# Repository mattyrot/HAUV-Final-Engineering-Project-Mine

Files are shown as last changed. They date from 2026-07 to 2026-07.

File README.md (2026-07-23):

# HAUV — Hybrid Autonomous Underwater Vehicle

A compact underwater robot you drive from a laptop with a game controller — or
point at a spot on the map and let it swim there by itself.

It runs **ROS 2 Foxy** across two computers, talks to **QGroundControl** over
either an Ethernet tether or an **acoustic (USBL) link**, and looks after itself
with a leak failsafe that surfaces the vehicle without any help from the operator.

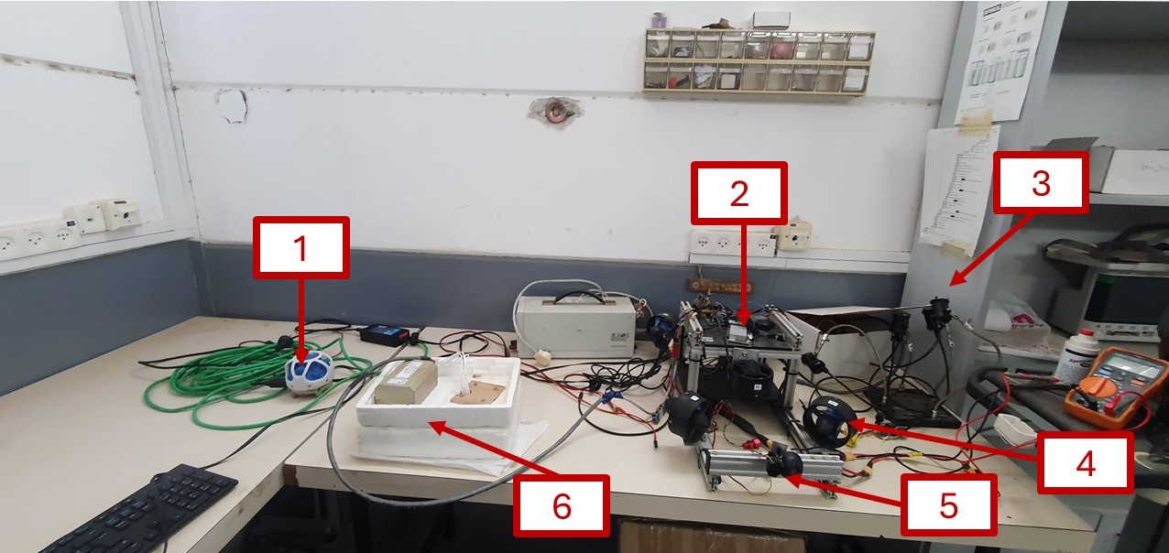
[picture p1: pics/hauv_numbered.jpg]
The HAUV and its main parts


| # | Part | What it does |
|---|---|---|
| 1 | **Subsonus (USBL modem)** | Acoustic link to the surface — control with no cable |
| 2 | **Electronics tray** | The two computers and their boards |
| 3 | **Lights** | Two switchable sets |
| 4 | **Thrusters** | 6 × Blue Robotics T200 |
| 5 | **Camera** | Live video to the operator screen |
| 6 | **DVL** | Speed over the sea floor |

---

## Highlights

- **Two control links** — Ethernet tether (full telemetry + video) or acoustic
  USBL (compact telemetry, no cable, no video).
- **Auto-GOTO / Guided mode** — click a point in QGC, the vehicle turns, swims
  there, **holds depth** on the way and **station-keeps** on arrival.
- **Leak → auto-surface failsafe** — runs on the vehicle itself, so it still
  works with the link cut.
- **Link-loss failsafe** — thrusters stop if the operator link goes quiet.
- **Attitude safety envelope** — scales back thrust when pitch/roll get extreme.
- **One-command operation** — `./hauv.sh` starts, checks and inspects everything.

---

## Architecture

Work is split across two computers. Knowing which does what makes debugging much
faster.

| Computer | Role |
|---|---|
| **UP Board** (Ubuntu 20.04, ROS 2 Foxy) | The brain — guidance, sensor fusion, navigation, QGC telemetry |
| **ESP32** (micro-ROS over serial) | The muscles — motor PWM, lights, and the depth / IMU / leak sensors |

```
ESP32 sensors ──micro-ROS──> /esp32/bno055_data, /esp32/bar100_data, /esp32/leak
DVL (Ethernet) ────────────> /dvl/velocity_data
GPS ───────────────────────> /gps/fix
Joystick / QGC ────────────> /joy  |  /joy_acoustic
                                      │
                                guidance_node
                                      │
                /motor_data, /lights_servo_data ──> ESP32 PWM outputs
                                      │
                    mavlink_bridge_node ──> QGC   (Ethernet, UDP 14550)
                    acoustic_bridge_node ─> QGC   (acoustic link)
```

### Inside the electronics tray

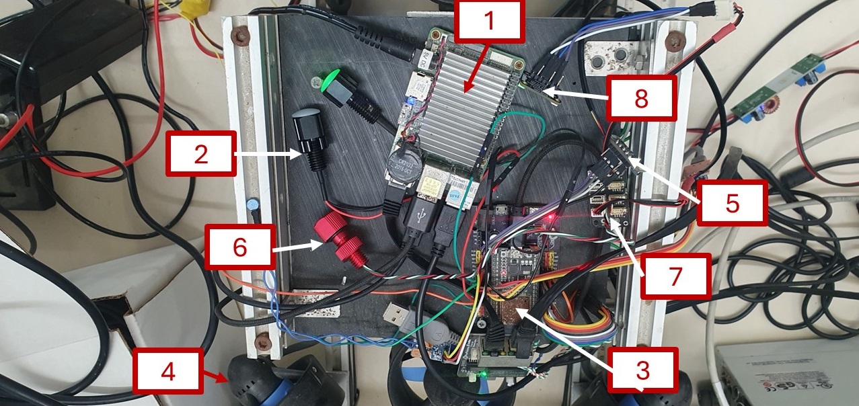
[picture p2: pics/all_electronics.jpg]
Electronics tray


| # | Board |
|---|---|
| 1 | **UP Board** — the main computer (large heatsink) |
| 2 | **Indicator light** — solid = ESP32 talking to ROS 2, off = link down |
| 3 | **ESP32** — real-time motor and sensor controller |
| 4 | **Thruster**|
| 5 | **BNO05** — IMU |
| 6 | **BAR100** - Pressure Sensor |
| 7 | **I²C Bus Splitter**  |
| 8 | **BME280** - Temprature Sensor|
---

## Quick start

Everything is driven by one script on the UP Board:

```bash
./hauv.sh start              # start the full stack (Ethernet / tethered)
./hauv.sh start --acoustic   # start in acoustic mode (no cable)
./hauv.sh check              # sample every sensor, report OK / LOW / FAIL
./hauv.sh status             # what's running
./hauv.sh topics             # live topics and their short names
./hauv.sh echo DEPTH         # stream one topic (no ros2 CLI needed)
./hauv.sh view guidance      # attach to a node's log  (Ctrl-A D to detach)
./hauv.sh stop
```

> `check` and `echo` use a direct rclpy subscriber rather than `ros2 topic echo`,
> because DDS CLI discovery is unreliable on this box — topics can look empty
> while they are actually publishing.

The DVL reports **FAIL** out of the water. That's expected — it needs water and
a bottom to range against.

---

## Connecting QGroundControl

### Over Ethernet (normal)

Set your laptop to `192.168.168.100`, then add a UDP link to
`192.168.168.101:14550`:

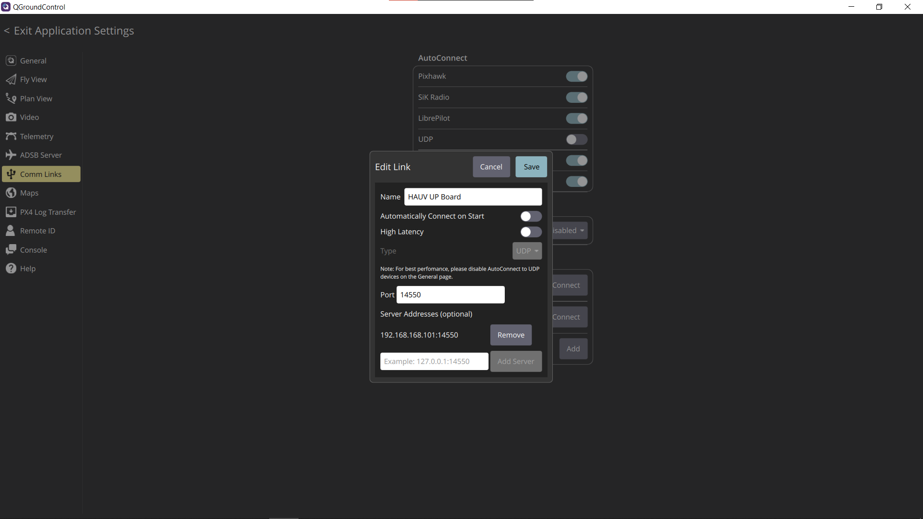
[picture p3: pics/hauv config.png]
QGC comm link setup


> Turn **AutoConnect → UDP** *off* in QGC's General settings, or it may grab the
> wrong endpoint and the vehicle will look dead.

### Over acoustic (untethered)

Both Subsonus units must be **in the water**. Start the vehicle with
`./hauv.sh start --acoustic`, then run **one** instance of the PC-side bridge and
point QGC at `127.0.0.1:14551`:

```bash
python tools/acoustic_qgc_bridge.py
```

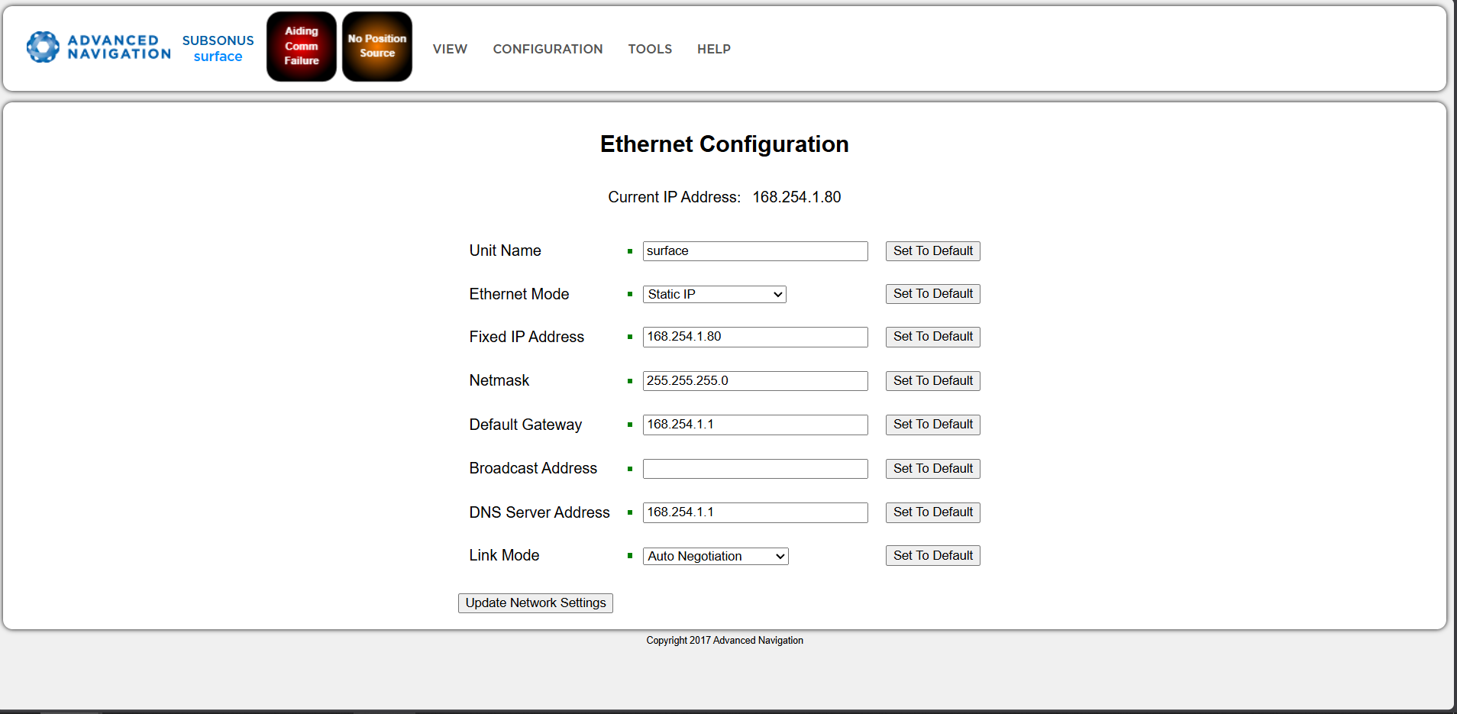
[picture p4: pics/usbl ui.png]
Subsonus configuration


### Flying

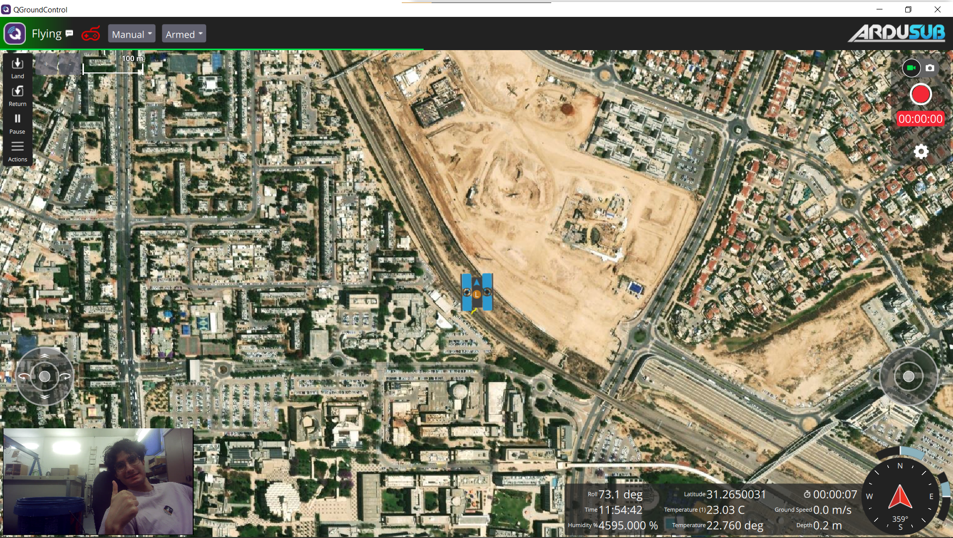
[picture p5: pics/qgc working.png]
QGC fly view


Telemetry, compass, video and warning banners all appear here. Alerts worth
knowing:

| Message | Meaning |
|---|---|
| `LEAK! Auto-surfacing` | Water inside. The vehicle is already ascending by itself — recover it. |
| `ACOUSTIC LINK LOST` | Modems can't hear each other. Check both are powered and submerged. |
| `FAIL: <sensor>` | That sensor stopped reporting. |

---

## Controls

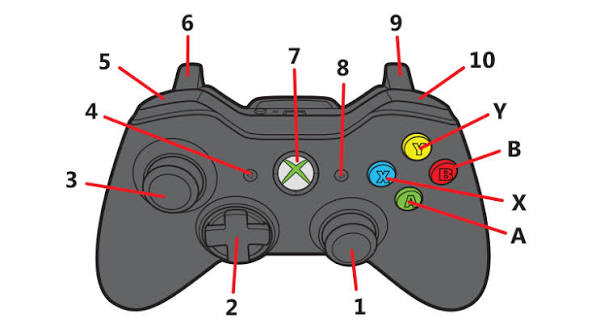
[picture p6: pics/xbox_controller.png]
Controller mapping


| # | Control | Action |
|---|---|---|
| 3 | Left stick | Forward / back, and strafe sideways |
| 1 | Right stick | Turn (yaw), and ascend / descend |
| A | A button | Toggle one set of lights |
| B | B button | Toggle the other set of lights |
| 5 | LB | Camera tilt up |
| 10 | RB | Camera tilt down |

Any stick movement cancels Guided mode and returns control to you.

### Flight modes

| Mode | Behaviour |
|---|---|
| **Manual** | You control everything. |
| **Stabilize** | Holds attitude level while you drive. |
| **Guided** | *Go to location* — drives to a clicked point, holds depth, then station-keeps until you take over. |

---

## Power

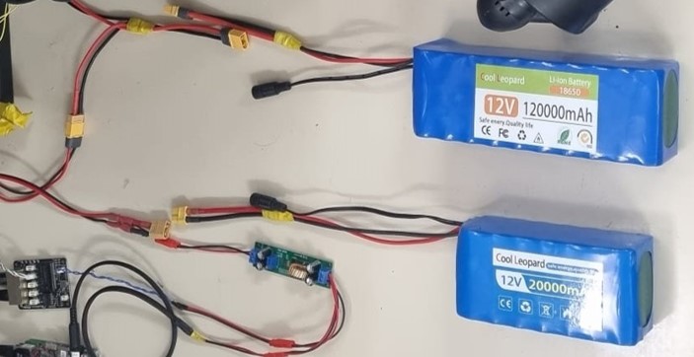
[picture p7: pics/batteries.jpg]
Battery wiring


Two 12 V lithium packs — one for the computers, one for the thrusters — joined
with XT-style plugs. The small green board steps 12 V down for the electronics.

> **Never** join red to black. Always power the vehicle off before connecting or
> carrying it, and never charge a hot or swollen pack unattended.

---

## Devices and addresses

| Device | Address / Port |
|---|---|
| UP Board | `192.168.168.101` |
| DVL | `192.168.168.102` (cmd 1033, binary 1034, string 1037) |
| Operator PC | `192.168.168.100` |
| Subsonus (surface) | `168.254.1.80` |
| QGC MAVLink | UDP `14550` (Ethernet) / `14551` (acoustic bridge) |
| ESP32 serial | the `ttyUSB*` with `ID_VENDOR=Silicon_Labs` — auto-detected |
| BNO055 IMU | I²C `0x28` |

Static IPs on `192.168.168.x/24`. Keep `ROS_DOMAIN_ID` identical on every
machine (`export ROS_DOMAIN_ID=0`).

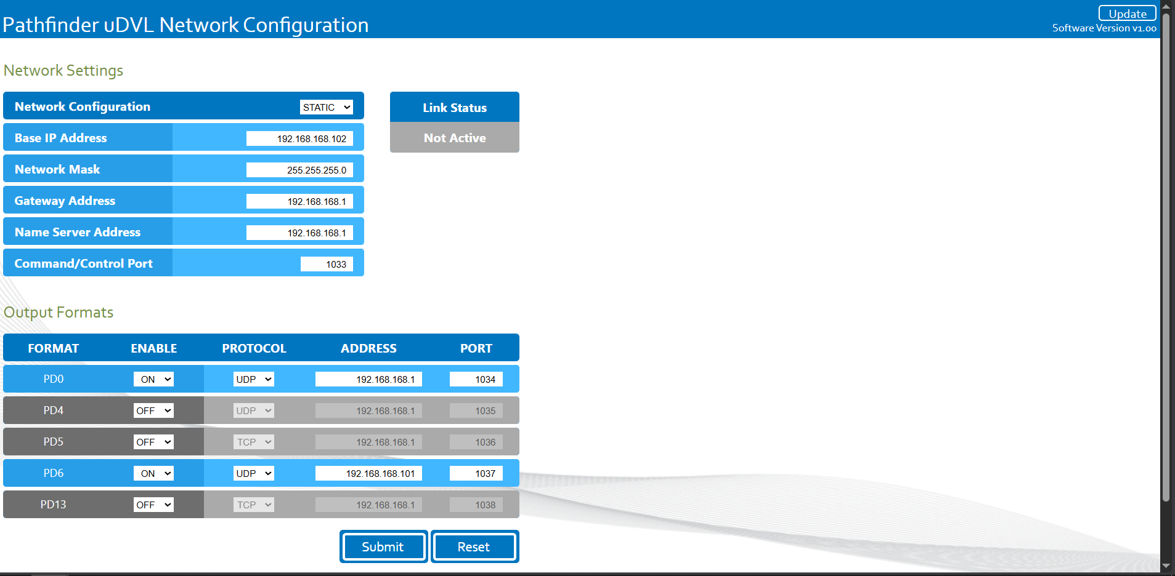
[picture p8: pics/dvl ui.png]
DVL configuration


---

## Packages

| Package | Contents |
|---|---|
| `autopilot_pkg` | `guidance_node` (modes, PID, motor mixing, GOTO, leak failsafe), `dvl_node`, `subsonus_node`, `acoustic_bridge_node`, `health_monitor_node` |
| `mavlink_bridge_pkg` | ROS 2 ↔ QGC MAVLink over UDP |
| `camera_pkg` | USB camera → `/camera_image` |
| `gps_pkg` | u-blox GPS → `/gps/fix` |
| `my_launch_pkg` | Launch files |
| `esp_sketches/rov_esp_main` | ESP32 firmware (micro-ROS) |

### Key topics

| Topic | Type | Notes |
|---|---|---|
| `/esp32/bno055_data` | `geometry_msgs/Twist` | `linear.x/y/z` = yaw / pitch / roll |
| `/esp32/bar100_data` | `geometry_msgs/Vector3` | `x` = depth (m), `y` = pressure, `z` = temp |
| `/esp32/leak` | `std_msgs/Float64` | `0.0` dry, `1.0` leak |
| `/motor_data` | `geometry_msgs/Twist` | Motors 1–6 as PWM µs (1100–1900, neutral 1500) |
| `/lights_servo_data` | `geometry_msgs/Vector3` | light1, light2, camera servo angle |
| `/guidance/goto_target` | `sensor_msgs/NavSatFix` | Guided-mode destination |

> `Twist` is used two different ways: on `/motor_data` the fields are **motor
> PWM values**, on `/dvl/velocity_data` they are **velocities**. Check the topic
> before interpreting the fields.

---

## Building

```bash
colcon build                                  # whole workspace
colcon build --packages-select autopilot_pkg  # one package
colcon test --packages-select autopilot_pkg   # lint + style
```

### ESP32 firmware

```bash
arduino-cli compile --fqbn esp32:esp32:esp32da src/esp_sketches/rov_esp_main/rov_esp_main.ino
arduino-cli upload -p /dev/ttyUSB0 --fqbn esp32:esp32:esp32da src/esp_sketches/rov_esp_main/rov_esp_main.ino
```

After flashing, restart the micro-ROS agent **with a DTR reset** — otherwise the
subscriptions come up dead and the motors won't respond.

### Deploying Python changes

The running code lives in the **install** tree, not `src`:

```
install/<pkg>/lib/python3.8/site-packages/<pkg>/<file>.py
```

---

## Troubleshooting

| Symptom | Try |
|---|-----|
| QGC won't connect | Check the cable, laptop IP `192.168.168.100`, `ping 192.168.168.101`, AutoConnect-UDP off |
| Vehicle visible but won't move | ESP32 ↔ ROS link down — check the green indicator, then `./hauv.sh restart` |
| No video | Video is Ethernet-only; it never runs over the acoustic link |
| DVL says FAIL | Normal out of water |
| `ACOUSTIC LINK LOST` | Both modems submerged and powered? Only **one** PC bridge running? |
| Sensors missing | `./hauv.sh check` to see which, then `./hauv.sh restart` |

```bash
ros2 topic list
ros2 topic hz /esp32/bno055_data
lsof | grep /dev/ttyUSB0        # who owns the serial port
sudo journalctl -u rov_nodes.service -f
```

---

## Acknowledgments

- **Prof. Hugo Guterman**, project advisor.
- **Ben-Gurion University**, Department of Electrical and Computer Engineering.

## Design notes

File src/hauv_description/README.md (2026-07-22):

# hauv_description

URDF model, meshes and RViz2 visualisation for the HAUV.

**Visualisation only — there is no physics here.** It displays measured state:
the thrusters spin to match what `guidance_node` is commanding, and the hull
rolls, pitches, turns and sinks to match the real IMU and depth sensor. For
thrust → motion you need Gazebo (on Foxy that means Gazebo Classic 11 with
hand-written buoyancy and thruster plugins).

## Running it

```bash
# live - mirrors the real vehicle
DISPLAY=:0 ros2 launch hauv_description display.launch.py

# offline - no vehicle needed
DISPLAY=:0 ros2 launch hauv_description display.launch.py live:=false

# headless - no RViz, just the model + TF (useful for checking the pipeline)
ros2 launch hauv_description display.launch.py rviz:=false
```

Over SSH there is no `DISPLAY`, so prefix with `DISPLAY=:0` to use the UP
Board's own screen, or RViz aborts with "cannot connect to X server".

| Argument | Default | Meaning |
|---|---|---|
| `live` | `true` | Hull pose from the real IMU + depth sensor |
| `rviz` | `true` | Also start RViz2 |
| `zero_on_start` | `true` | Treat the first pitch/roll reading as level |

## What each node does

| Node | Job |
|---|---|
| `robot_state_publisher` | Turns the URDF + `/joint_states` into the TF tree |
| `motor_to_joint_states` | `/motor_data` (PWM) → `/joint_states`, so the thrusters spin |
| `attitude_to_tf` | Real BNO055 attitude + BAR100 depth → `world`→`base_link` TF |

`motor_to_joint_states` runs in **both** modes. It publishes at 30 Hz whether or
not `/motor_data` is arriving, so the six continuous joints always have a
transform. That is deliberate — `joint_state_publisher` is **not installed** on
this box, and this node covers the same need.

`zero_on_start` matters in practice: the vehicle is rarely sitting flat on the
bench (it read pitch −17.6°, roll 72.8° during testing), and without levelling
the model looks permanently capsized. Yaw is never zeroed — it is a real heading.

If the model climbs when the vehicle dives, set `invert_depth:=true` on
`attitude_to_tf`. Depth is positive-down and world Z is up, so `z = -depth` is
the expected mapping and was confirmed correct during testing.

## Two install quirks on this box

**1. colcon puts the entry points in the wrong place.** It installs
`console_scripts` to `install/hauv_description/bin/` instead of
`install/hauv_description/lib/hauv_description/`, which breaks both `ros2 run`
and `Node(executable=...)` in the launch file. Same quirk CLAUDE.md documents
for `mavlink_bridge_pkg`. After every `colcon build`:

```bash
D=~/rov_ws/install/hauv_description
mkdir -p $D/lib/hauv_description
cp -f $D/bin/motor_to_joint_states $D/bin/attitude_to_tf $D/lib/hauv_description/
chmod +x $D/lib/hauv_description/*
```

**2. `rviz2` cannot render on the UP Board's own screen (`DISPLAY=:0`).**
Run it over X forwarding to a PC instead — that works.

It segfaults on `:0`. A gdb backtrace pins it exactly:

```
#3  Ogre::GLRenderSystem::GLRenderSystem()      <- legacy GL render system ctor
#2  … std::string::operator=  -> SEGFAULT
```

GLX context creation on the local display fails first (`XCB error 148, major
code 140`), so `glGetString` hands Ogre a **NULL**, and assigning NULL to a
`std::string` segfaults. It is not the model, the meshes, the triangle count or
memory — an empty scene with `LIBGL_ALWAYS_SOFTWARE=1` crashes identically.
`QT_X11_NO_MITSHM`, `QT_XCB_GL_INTEGRATION=none` and `QT_OPENGL=software` do not
help, and reinstalling all five rviz packages changed nothing. `rviz_rendering`
hardcodes `RenderSystem_GL`, so the working `RenderSystem_GL3Plus.so` sitting
next to it cannot be selected by configuration.

**The fix — X forwarding.** Start an X server on the PC (VcXsrv / XLaunch), then:

```bash
# from the PC, with the X server running
DISPLAY=localhost:0.0 ssh -Y up@192.168.168.101
# then on the board:
source /opt/ros/foxy/setup.bash && source ~/rov_ws/install/setup.bash
ros2 launch hauv_description display.launch.py
```

Verified working: RViz opens on the PC and the model tracks the live vehicle.
VcXsrv's GLX returns proper driver strings, so Ogre initialises normally.

Keep the SSH session open — the X tunnel dies with it. Note this pushes all
geometry over indirect GLX, so the 2 M triangles are being sent across the
network; if it drags, decimate the meshes (see below).

Caveat for a *headless* board: with no monitor and no forwarding there is no
display at all, and RViz cannot run. `rviz2 --help` also fails in that case —
it initialises Qt even for `--help`, so "`--help` aborts" means "no DISPLAY",
**not** "broken binary".

## Verified headless

With `rviz:=false` the whole pipeline checks out on the vehicle:

- `robot_state_publisher` loads all 16 segments from the URDF
- `/joint_states` carries all six thruster joints
- `world`→`base_link` TF tracks the real sensors — TF `z = +0.269` against a raw
  depth reading of `−0.269`, and rotation ≈ identity after levelling

So when RViz runs anywhere, it will just work. Because ROS 2 is networked, RViz
does **not** have to run on the vehicle — any machine on the same
`ROS_DOMAIN_ID` can subscribe to `/robot_description`, `/joint_states` and `/tf`
and render the model on a decent GPU. That is the better arrangement anyway: the
UP Board is a weak, headless vehicle computer.

## Model notes

Frame: **X forward, Y port, Z up**, origin on the pressure-tube axis, centred
fore-aft — the same frame the CAD and the thrust-allocation matrix use.

16 links, 15 joints, single root `base_link`. Six `continuous` thruster joints
about their own +X; lights, Subsonus, Bar30 and the indicator are `fixed`;
`camera_link` and `dvl_link` are empty reference frames.

Meshes are exported from Fusion in **millimetres**, so every one carries
`scale="0.001 0.001 0.001"`. Delete that and the vehicle renders 1000× too big.

**Size:** ~29 MB of STL, ~2.03 M triangles (T200 186k × 6, Lumen 164k × 4,
Subsonus 200k). That was never reached during testing because RViz crashed
first, so its real frame rate here is still unknown. If it drags once RViz
works, decimate those three vendor meshes in Blender (Decimate modifier, ~0.1
ratio) — visual meshes do not need machining fidelity.

**The thruster mesh is the whole T200**, so spinning a joint turns the duct with
the rotor. Splitting the propeller bodies out of `T200.STEP` into their own mesh
and child link would fix it — a small export job, not a redesign.

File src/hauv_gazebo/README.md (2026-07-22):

# hauv_gazebo

Gazebo Classic 11 simulation of the HAUV, wired so **`guidance_node` flies the
simulated vehicle unmodified** — it reads the same `/esp32/*` and `/gps/fix`
topics and writes the same `/motor_data` it uses on hardware.

## Where it runs

**WSL `Ubuntu-Foxy`, not the UP Board.** The UP Board is a 4-core Atom that
already sits at load ~4.4 encoding video; Gazebo would bury it, and the vehicle
computer should not be running a simulator. WSL has Gazebo 11.11, ROS 2 Foxy,
all four `gazebo_ros` plugin libraries, and 6 cores.

```bash
# build / re-sync after editing on the Windows side
wsl -d Ubuntu-Foxy -- bash "/mnt/c/Users/matma/Desktop/rov_ws - Copilot/src/hauv_gazebo/wsl_build.sh"

# run headless (light, good for control testing)
source /opt/ros/foxy/setup.bash && source ~/hauv_sim_ws/install/setup.bash
ros2 launch hauv_gazebo hauv_sim.launch.py gui:=false

# with the Gazebo GUI - needs an X server (VcXsrv/XLaunch), same as RViz
DISPLAY=<your-windows-ip>:0 ros2 launch hauv_gazebo hauv_sim.launch.py
```

Source lives in the Windows repo (versioned with everything else); the build
happens on the WSL filesystem because building across `/mnt/c` is painfully slow.

| Argument | Default | Meaning |
|---|---|---|
| `gui` | `true` | Run `gzclient` |
| `bridges` | `true` | Run the thruster/sensor bridges |
| `spawn_z` | `-0.15` | Spawn depth (world Z, negative = under water) |
| `publish_leak` | `true` | Let `sensor_bridge` synthesise `/esp32/leak=0.0`. Set `false` to inject a leak yourself |

## Flying it yourself, from the keyboard

**Run this in a real WSL terminal** — it reads keys from the terminal, so it
cannot be driven through a pipe or a tool:

```bash
wsl -d Ubuntu-Foxy
bash "/mnt/c/Users/matma/Desktop/rov_ws - Copilot/src/hauv_gazebo/fly_sim.sh"
bash ".../fly_sim.sh" headless        # no Gazebo window
```

That starts the sim, both bridges and `guidance_node`, then hands you:

```
 arrow up/down     forward / reverse        w / s   ascend / descend
 arrow left/right  turn left / right        a / d   strafe left / right
 space  ALL STOP        + / -  speed scale        q  quit
```

Controls are **sticky** — a key sets the thrust and it holds until you change it
or press space. A terminal reports key presses but never releases, so
hold-to-drive would stutter on the auto-repeat delay; sticky also suits a vehicle
that takes several seconds to accelerate.

There is no gamepad option, and it is not worth chasing: WSL has no
`/dev/input`, no USB passthrough and no loadable kernel modules, so `joy_node`
cannot see a controller without rebuilding the WSL kernel. The keyboard arrives
on stdin, which WSL has always had. `teleop_key` publishes `/joy` in exactly the
shape `joy_node` would, so `guidance_node` cannot tell the difference.

## Flying guidance_node

`run_guidance_test.sh` brings up the sim, both bridges, `guidance_node` and a
scripted pilot, runs one scenario, tears it all down and prints PASS/FAIL:

```bash
wsl -d Ubuntu-Foxy -- bash ".../run_guidance_test.sh" manual      # drive every axis
wsl -d Ubuntu-Foxy -- bash ".../run_guidance_test.sh" depth_hold  # hold against the buoyant trim
wsl -d Ubuntu-Foxy -- bash ".../run_guidance_test.sh" goto        # turn, transit 29 m, loiter, abort
wsl -d Ubuntu-Foxy -- bash ".../run_guidance_test.sh" leak        # auto-surface failsafe
```

All four features work: **23 of 24 checks pass**. The one failure is deliberate —
it flags a real `guidance_node` defect (out-of-range PWM on two-axis stick input,
see `DEVELOPMENT.md`), and is left failing rather than softened. Logs and a CSV
of every run land in `/tmp/hauv_sim_results/`.

**There is no joystick in WSL, and `guidance_node` will not fly without one.**
Its `_last_joy_time` starts at 0.0, so `JOY_FAILSAFE_TIMEOUT` (1.5 s) zeroes
manual thrust and `GOTO_COMMS_TIMEOUT` (5 s) *aborts auto-GOTO* before you ever
see it navigate. `sim_pilot` stands in for both the joystick and QGC: it
publishes `/joy` at 20 Hz throughout, and injects `/guidance/goto_target`
exactly as `mavlink_bridge_node` does on "Go to location".

Depth-dependent scenarios spawn deep on purpose. At the default `-0.15` m the
vehicle parks against the surface slab at ~0.066 m, the depth error never leaves
`GOTO_DEPTH_DEADBAND` (0.3 m), and depth hold "passes" by doing nothing.

## What it gives you

| Topic | Direction | Notes |
|---|---|---|
| `/motor_data` | in | PWM 1100–1900 from guidance → thruster forces |
| `/esp32/bno055_data` | out | From the simulated IMU, degrees, yaw as 0–360 heading |
| `/esp32/bar100_data` | out | Depth from the model's Z (positive down) |
| `/esp32/leak` | out | Synthesised dry; `publish_leak:=false` to inject a leak by hand |
| `/gps/fix` | out | Model position → lat/lon, so auto-GOTO has something to chase |

## Measured behaviour

```
forward   0.971 m/s    yaw   ~26 deg/s (pure rotation)
reverse   0.919 m/s    vertical  1.11 m/s up / 0.86 m/s down
neutral   drifts up ~0.016 m/s (see limitations)
```

Driven through `guidance_node` at full stick (which commands yaw harder than it
commands forward — `yaw·400` on all four horizontals vs `400·cos45` for surge):

```
forward   0.99 m/s, but pitches nose-up 17.5 deg and CLIMBS at 0.30 m/s
strafe    1.00 m/s to port         yaw   136 deg/s  <-- 5x the figure above
descend   0.85 m/s, pitches nose-down 21.8 deg
```

The forward-thrust climb and the yaw discrepancy are both open — see
`DEVELOPMENT.md`.

## Five bugs found and fixed getting here

Worth reading before trusting or changing the model.

**1. It sank — 4.8 kg negative (−47 N).** The buoyancy volume was the pressure
tube's CAD volume (0.006026 m³), not the vehicle's displacement. Trimmed to
0.010802 m³ → **+0.1 kg positive**, the correct ROV direction (surfaces on power
loss). The URDF header already called this out and prescribed ~7.7 L of foam.

**2. It capsized — centre of buoyancy 8 mm *below* centre of mass.** An inverted
pendulum: pitch ran 9°→32° in 40 s and never settled. `center_of_volume` z raised
to 0.045 (33 mm above CG) → settles stably at ~3°. Also the header's WARNING 2,
and the same fix it recommends (foam mounted high).

**3. `velocity_decay` was ~30× too strong.** Gazebo applies it **per timestep,
not per second**, so `0.20` at `dt=0.001` is a ~5 ms damping constant. Full
vertical thrust produced 0.001 m/s — slower than passive drift. Retuned to
`0.006 / 0.02` for ~1 m/s terminal.

**4. Thrust was applied along the wrong axis.** The joints declare
`axis="0 0 1"`, so the propeller spins about local **Z** and thrust acts along
**Z**, not X. Using `force.x` shoved the vertical pair *forwards* below the
centre of mass — "full vertical thrust" produced a ±20° pitching couple and no
vertical motion.

**5. Two separate mapping/geometry errors cancelled the horizontal thrusters.**
- All four horizontals pointed **forward** (rear pair exported at 45° instead of
  135°), so guidance's `(+,+,−,−)` forward mixing summed to **exactly zero**.
  Rear pair rotated to ±135°.
- **Motors 4 and 6 were swapped** in the motor→thruster map (inherited from
  `motor_to_joint_states.py`, whose README admits the mapping was never
  verified). With them swapped, yaw commands came out as pure *strafe* — the
  four yaw moments cancelled. The correct assignment is derived from physics in
  `thruster_bridge.py`: `m1→t1, m3→t2, m6→t3, m4→t4`.

> **`hauv_description/motor_to_joint_states.py` still has the 4/6 swap.** It only
> spins propellers in RViz so nothing breaks visually, but it is wrong.

## Limitations — read before believing a result

- **The water surface is faked with a collision slab.** Gazebo's
  `BuoyancyPlugin` has no free surface and applies buoyancy at every height, so
  the vehicle used to rise forever (it reached z = +10 m — 10 m in the air,
  still "floating"). A static collision slab in `underwater.world` puts a
  ceiling at z = 0: the vehicle now rises, meets it and parks at depth
  ~+0.066 m indefinitely. It is a rigid contact, not surface dynamics — it
  touches and settles rather than bobbing, and nothing pushes it back down, so
  the vehicle cannot be launched from above the water. Spawn below z = 0 (the
  launch file does, at −0.15).
- **Buoyant ascent is slow, by design.** At +0.1 kg trim an uncommanded vehicle
  climbs ~1 cm/s, so recovering from 12 m takes ~20 minutes. That is realistic;
  use the vertical thrusters if you want to get up quickly.
- **Drag is linear and isotropic**, not quadratic, and there is **no added
  mass**. It was tuned at ~1 m/s and is only honest near there. Fine for
  exercising control loops; not a hydrodynamic model. Proper added mass needs a
  custom plugin — the modern gz-sim hydrodynamics stack targets Humble+, and
  this vehicle is on Foxy.
- **Vertical thrust induces pitch** (~±20° at full). Real: the thruster pair
  straddles a centre of mass that sits 22 mm aft of their midpoint, so equal
  thrust makes a couple. Trim the CG or expect the controller to handle it.
- The camera plugin needs rendering; headless logs harmless `CameraSensor` errors.

## colcon quirk

Entry points install to `install/hauv_gazebo/bin/` instead of
`lib/hauv_gazebo/`, which breaks `ros2 run` and launch. `wsl_build.sh` copies
them across automatically — same workaround as `hauv_description` and
`mavlink_bridge_pkg`.

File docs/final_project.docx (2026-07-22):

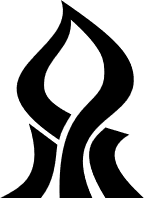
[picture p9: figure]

Ben-Gurion University of the Negev

Faculty of Engineering Science

School of Electrical and Computer Engineering

Dept. of Electrical and Computer Engineering

Fourth Year Engineering Project

Final Report

Design and Implementation of a Hovering Autonomous Underwater Vehicle (HAUV)

Project number: p-2026-126

Student: Matty Rotman - 314834367

Supervisor: Hugo Guterman

Submitting date: July 26th, 2026

# Table of Contents

# Abstract

Autonomous Underwater Vehicles (AUV) are self-contained robots that are capable of executing complex tasks in underwater environments with little to no direct human interactions.

Unlike conventional submarines, AUVs eliminate the need for complex human support systems, enhancing their efficiency and accessibility while providing superior maneuverability compared to submarines of comparable size.

The main goal of the project is to develop an unmanned hovering autonomous underwater vehicle, which, compared to its off-the-shelf counterparts, will be designed for improved accuracy and higher speeds.

The AUV will incorporate a Master-Slave architecture, an operator using an off the shelf command and control system will assign the AUV an objective, a location, and the AUV using its processing units will navigate to its designated destination in the shortest possible time while keeping its balance while conducting the required measurements using its onboard sensors, sending them real time to its operator.

Ultimately, a proof of concept (POC) will be realized, showcasing an AUV capable of operating in the open sea while being easily controlled with minimal human intervention.

Keywords: HAUV, Robotics, Command and Control, sensors, Autonomous, Data Processing, Stability Control, User Experience, Maneuverability, Sea Exploration.

תקציר

כלי רכב תת-ימיים (AUV) הם רובוטים עצמיים המסוגלים לבצע משימות מורכבות בסביבות ימיות עם מעט מאוד אינטראקציה ישירה עם בני אדם.

בניגוד לצוללות קונבנציונליות, AUV אינם דורשות מערכות תומכות חיים מורכבות, מה שמיעל אותן ומנגיש אותן תוך מתן יכולת תמרון עדיפה בהשוואה לצוללות בגודל דומה.

מטרת הפרויקט היא פיתוח כלי רכב תת-ימי אוטונומי מרחף בלתי מאויש (HAUV) אשר בהשוואה למקביליו המסחריים ייועד לדיוק גבוה יותר ולמהירויות גבוהות יותר.

ה-AUV בעל ארכיטקטורה מסוג Master-Slave, בה מפעיל משתמש במערכת שליטה ובקרה (שו"ב) מסחרית יקצה משימה ו-AUV על ידי שימוש במחשבים שלו ינווט ליעד המיועד בזמן הקצר ביותר תוך שמירה על יציבותו וביצוע המדידות הנדרשות באמצעות החיישנים המובנים שלו ולבסוף ישלח את הנתונים בזמן אמת למפעיל.

בסופו של הדבר תתבצע הוכחת היתכנות (POC) שיפתח AUV המסוגל לפעול בים הפותח תוך שליטה קלה במינימום התערבות אנושית.

מילות מפתח: HAUV, רובוטיקה, שליטה ובקרה, חיישנים, אוטונומיות, עיבוד נתונים, בקרת יציבות, חווית משתמש, יכולות תמרון, חקר ימי.

# Project Goals - Project Deliverables and Scope Definition

Building on the existing HAUV platform, this continuation project pursued the three goals defined in the preliminary design, restated here in the terms used for the final evaluation.

## Goal 1 — Autonomous Mission Execution

Goal: Perform a complete autonomous operation without direct human intervention.

Success criteria: The system successfully executes a complete area scan and marks a specific target in the final experiment while in autonomous-mission mode.

## Goal 2 — Operation Stability and Precision

Goal: Maintain high stability and navigation accuracy throughout the mission.

Success criteria: The system holds the key parameters, depth stability, mission-tracking accuracy and object-detection reliability, within the required operational thresholds.

## Goal 3 — Real-Time Control and Telemetry

Goal: Ensure continuous monitoring and a live data flow between the HAUV and the operator.

Success criteria: The system successfully measures and transmits real-time data from the onboard sensors to the operator.

# Project Deliveries

- Software and control system, a high-level control system running on the UP Board under the ROS 2 framework, together with a real-time control system on an ESP32 microcontroller for motor and sensor management.
- Simulation environment, a complete simulation of the HAUV on the ROS 2 Gazebo simulator, for validating movement, sensor data and control algorithms before physical implementation.
- Physical proof of concept, a functional HAUV integrating sensors, motor control and communications, aimed at navigation and stabilisation.

## In Scope

- Development of stability and navigation control algorithms.
- Integration of navigation sensors.
- Validation through simulation and testing.
- Implementation of communication between the HAUV and the operator.

## Out of Scope

- Mechanical chassis fabrication, the HAUV's chassis is produced by a separate mechanical team.
- Full waterproofing and open-sea trials, the prototype is not water-resistant, so testing in open-sea conditions was not conducted.

# Introduction

Autonomous Underwater Vehicles (AUVs) are self-contained robots capable of executing complex tasks in underwater environments with little to no direct human interaction. First developed in the late 1950s, the Self-Propelled Underwater Research Vehicle (SPURV) operated at 2.2 m/s for 5.5 hours, the field has since matured from specialised research platforms into versatile, modular systems, and AUVs are today a standard tool in academic and industrial work ranging from seafloor mapping to environmental monitoring [1].

While AUVs have become increasingly affordable and capable, commercially available hovering AUVs (HAUVs) such as the Blue Robotics BlueROV2 are designed as general-purpose systems that prioritise rated depth, operational range and ease of use over extreme precision or high-speed, tailored manoeuvres. This performance gap motivates a bespoke HAUV whose thruster configuration and control algorithms are optimised specifically for improved accuracy and higher speed [2].

Locating an underwater vehicle with GPS is largely ineffective, because high-frequency electromagnetic waves attenuate rapidly even at shallow depths, and GPS spoofing and jamming add reliability and security concerns. Acoustic methods are used instead: a Doppler Velocity Log (DVL) estimates the vehicle's velocity relative to the seafloor from the Doppler shift of emitted acoustic pulses, and fusing this with inertial measurements yields position over time without surfacing, while acoustic beacons provide absolute positioning by time-of-flight [3]. High-level processing runs on an Intel-based UP Board; ARM platforms such as the Raspberry Pi offer an alternative with lower power and heat and a path to an on-board AI module for computer-vision tasks [4].

The control software is built on the Robot Operating System 2 (ROS 2) together with the Gazebo simulation environment, which allows models and logic developed in simulation to be deployed onto the hardware with few modifications and enables risk-free testing by replicating underwater conditions before the vehicle enters the water [5]. The command-and-control link between the HAUV and its operator is bridged by the MAVLink protocol through the QGroundControl (QGC) station, a lightweight, vehicle-agnostic, cross-platform interface whose extensible mission-planning support suits the bespoke autonomous missions required here [6].

This continuation project builds on the earlier stage of the work, which delivered a bench prototype of the dual-computer, ROS 2-based HAUV but left it operated through custom scripts over a wired link, without autonomous point-to-point navigation or an untethered control path, and with several sensor drivers inoperative. The present work integrates the vehicle with QGroundControl through a purpose-built MAVLink bridge, adds a fully autonomous Guided (go-to-location) mode with depth hold and station-keeping, introduces an acoustic (USBL) control channel for cable-free operation, integrates the DVL for velocity, and implements on-board leak, link-loss and attitude failsafes, all while retaining the dual-processor design in which a Linux UP Board runs high-level guidance and telemetry and an ESP32 microcontroller handles real-time motor and sensor tasks.

# Final Technical Specifications

The overall architecture of the HAUV, how power and data are distributed across the vehicle, is summarised in the block diagram below.

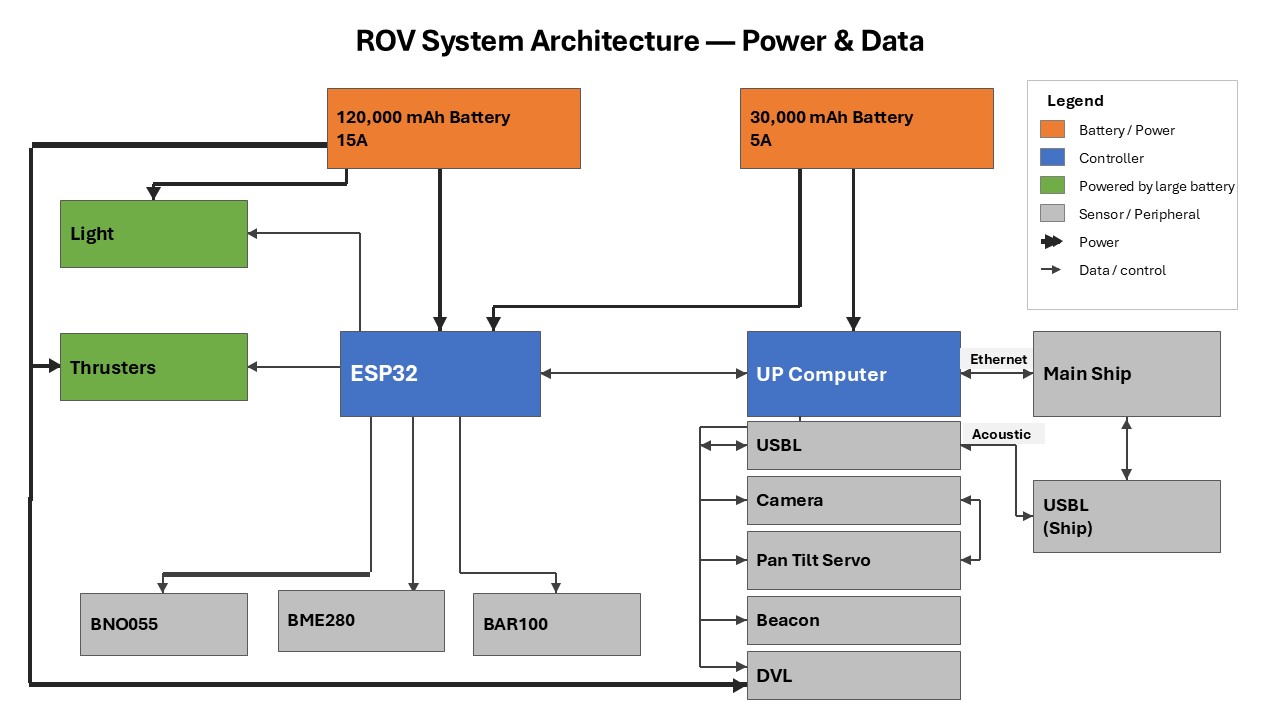
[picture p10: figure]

Figure 1 — HAUV system block diagram: power distribution and data/control paths.

The vehicle retains the physical platform and core sensor suite of the earlier stage; the specifications below consolidate that platform with the computing, communication and software additions delivered in this project.

## 1. Physical Characteristics

- Dimensions: 70 cm x 25 cm x 20 cm
- Frame material: Vslot aluminium profiles
- Manoeuvrability: hovering-class, multiple degrees of freedom (surge, sway, heave, yaw, pitch)

## 2. Propulsion

- Thrusters: 6 × Blue Robotics T200
- Configuration: two front and two rear thrusters angled inward at 45°, plus one front and one rear vertical thruster
- Motor command: PWM in microseconds, neutral 1500 µs, full range 1100–1900 µs; all thrusters initialised to 1500 µs before operation

## 3. Sensors

- GPS: u-blox receiver providing a surface position fix for the navigation core
- Depth, temprature & pressure water resistant: Blue Robotics BAR100
- Temperature & humidity: Bosch BME280 electronics monitoring.
- Leak sensor: Blue roboticsleak sensor with 4 probes.
- Doppler Velocity Log (DVL): Teledyne Pathfinder for velocity over the seafloor.
- Inertial Measurement Unit (IMU): Bosch BNO055 for orientation data.
- Accostic position and communication: Advanced Navigation Subsonus.

## 4. Processing Units

- Main computer, UP Board: Ubuntu 20.04 with ROS 2 Foxy for high-level guidance, sensor fusion, navigation and QGC telemetry
- Real-time microcontroller, ESP32: runs micro-ROS for motor PWM, lights and real-time sensor acquisition
- Division of labour: the UP Board handles autonomy and communication; the ESP32 guarantees deterministic, low-latency motor and sensor timingx

## 5. Communication and Networking

- Ethernet (TCP/IP): Primary tethered link. Carries DVL data and general above-/below-water communication through the Blue Robotics Ethernet switch, and transports QGC MAVLink telemetry over UDP.
- Acoustic (USBL): Untethered link over a pair of Subsonus acoustic modems. Carries compact telemetry and operator commands (no video), allowing cable-free operation.
- UART (serial): UP Board ↔ ESP32 over micro-ROS at 115200 baud; a separate FTDI UART is used for ESP32 debug output.
- I²C: ESP32 ↔ all environmental/orientation sensors (BNO055, BAR100, BME280) through a Blue Robotics I2C Bus Splitter board.
- 5 V PWM: Drives the thruster ESCs, camera pan-tilt servo and the lights.

The system uses static IP addresses on the 192.168.168.x/24 subnet, with a common ROS_DOMAIN_ID across all machines. The key devices and endpoints are summarised below.

Device | Address / Port
UP Board (main computer) | 192.168.168.101
Doppler Velocity Log (DVL) | 192.168.168.102, cmd 1033, binary 1034, string 1037
Operator PC / ground station | 192.168.168.100
Subsonus USBL (surface unit) | 168.254.1.80
Subsonus USBL (subsea unit) | 168.254.1.79
QGC MAVLink, Ethernet | UDP 14550
QGC MAVLink, acoustic bridge | UDP 14551 (127.0.0.1)
ESP32 serial | 115200 baud (Silicon Labs CP2102, auto-detected)

Table 1, Network devices and endpoints.

## 6. Power

- Battery 1: 12 V lithium pack powering the computing and electronics domain, UP Board, DVL, Ethernet switch and beacon.
- Battery 2: 12 V lithium pack dedicated to the thrusters and lights, isolating high motor currents from the sensitive electronics.
- DC-DC conversion: A step-down converter provides the regulated 5 V rail for the electronics from the 12 V supply.

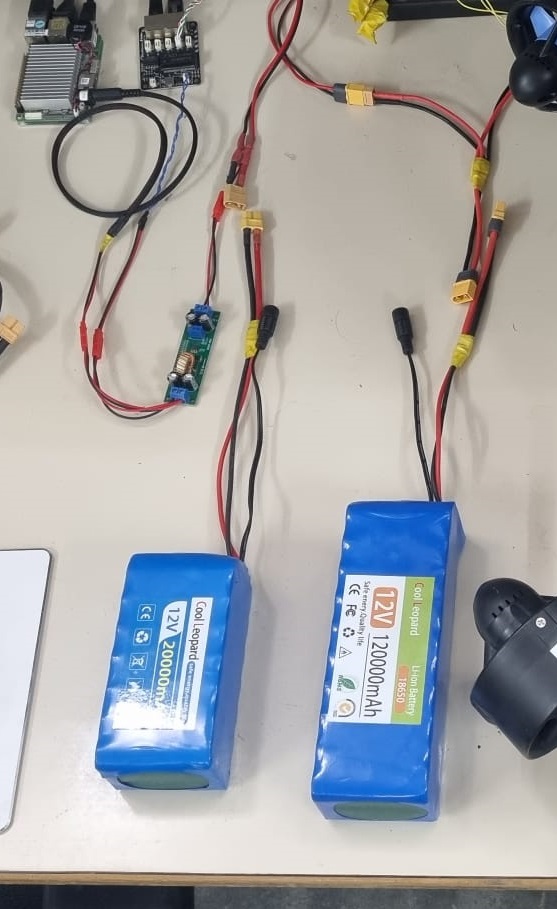
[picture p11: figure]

Figure 2 — The two 12 V lithium packs and the step-down converter (small green board).

## 7. Software Architecture and Packages

- Operating system: Ubuntu 20.04 on the UP Board, with ROS 2 Foxy as the robotics middleware coordinating all high-level tasks.
- Microcontroller framework: The ESP32 runs FreeRTOS with micro-ROS (Arduino), exchanging sensor and actuator data with the UP Board over the serial link.
- Operating tool: A single management script, hauv.sh, is the one entry point for running and inspecting the stack, start, stop, restart, check (per-sensor OK/LOW/FAIL health at rate), status, topics, echo and view.

The software is organised into ROS 2 packages, each with a well-defined responsibility:

Package | Responsibility
autopilot_pkg | guidance_node (mode switching, PID stabilisation, motor mixing, Guided/GOTO, leak failsafe), dvl_node, subsonus_node, acoustic_bridge_node, health_monitor_node
mavlink_bridge_pkg | Bridges ROS 2 topics to QGroundControl over UDP MAVLink
camera_pkg | USB camera → /camera_image
gps_pkg | u-blox GPS → /gps/fix
my_launch_pkg | Launch-file definitions
esp_sketches/rov_esp_main | ESP32 firmware (micro-ROS), sensor publishing and PWM outputs

Table 2, ROS 2 packages and responsibilities

Data flows between the vehicle's sensors, the guidance core and the ground station through a small set of ROS 2 topics:

Topic | Type | Notes
/esp32/bno055_data | Twist | linear.x/y/z = yaw / pitch / roll (BNO055)
/esp32/bar100_data | Vector3 | x = depth (m), y = pressure, z = temperature
/esp32/leak | Float64 | 0.0 = dry, 1.0 = leak
/dvl/velocity_data | Twist | linear.x/y/z = velocity over ground
/motor_data | Twist | Motors 1–6 as PWM µs (1100–1900, neutral 1500)
/lights_servo_data | Vector3 | light 1, light 2, camera-servo angle
/guidance/goto_target | NavSatFix | Guided-mode destination

Table 3, Key ROS 2 topics

# Approach Taken to Solve the Problem and Engineering Design

The goal of this stage was to turn the existing HAUV platform into a vehicle that can be operated from a standard ground station, navigate autonomously, and protect itself in a fault. Reaching it meant reuse of the existing hardware, new software subsystems for control and communication, and putting it through rigorous testing.

## System Architecture

The HAUV keeps a dual-computer architecture that cleanly separates deterministic low-level control from higher-level autonomy. The system is composed of three main subsystems:

- Ground station: An operator running QGroundControl on a PC, connected to the vehicle either over the Ethernet tether or over the acoustic (USBL) link.
- Underwater pressure vessel: Houses the core electronics, the UP Board and the ESP32, together with the orientation, depth and environmental sensors.
- Underwater components: The exposed hardware: six T200 thrusters, the lights, the camera, the DVL and the acoustic beacon.

The system splits across two computers, the UP Board (ROS 2) for high-level guidance, navigation and QGC telemetry, and the ESP32 (micro-ROS) for real-time motor, light and sensor control, linked by a guidance_node that fuses the inputs and a bridge node that relays telemetry over Ethernet or the acoustic link.

## Design Components

The core electronics are mounted together on the vehicle's electronics tray:

- UP Board, the main computer (identifiable by its large heatsink).
- Indicator light, solid when the ESP32 is communicating with ROS 2; off when the link is down.
- ESP32, the real-time motor and sensor controller.
- Thruster (one of six Blue Robotics T200 units).
- I²C connector, to the environmental/temperature sensor, via the custom breakout board.
- GPS antenna, surface fix used as the origin for navigation.

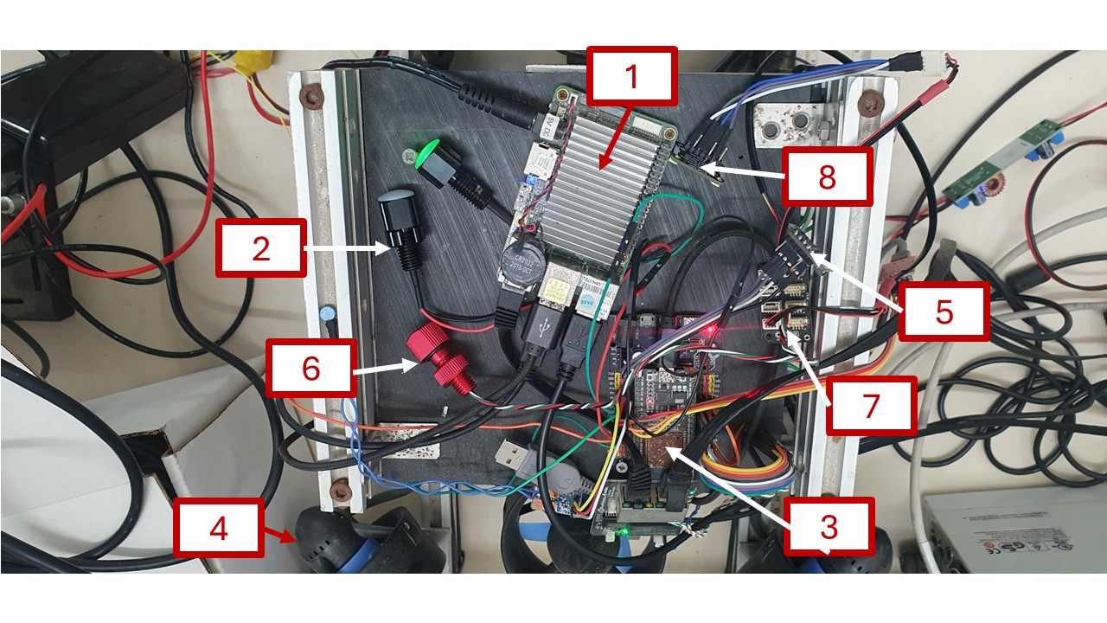
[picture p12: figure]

Figure 3 Electronics:(1) UPBoard, (2) indicator, (3) ESP32, (4) thruster, (5) BNO055, (6) BAR100, (7) I2C board, (8) BME.

## Doppler Velocity Log (DVL) Integration

Precise underwater navigation depends on an accurate velocity measurement, which cannot be obtained reliably by integrating accelerations over time. A Teledyne Pathfinder Doppler Velocity Log (DVL) was integrated to measure the vehicle's velocity relative to the sea floor directly. The dvl_node connects to the DVL over Ethernet (192.168.168.102), parses its output over UDP in its PD6 format and republishes it on /dvl/velocity_data for the guidance core and the telemetry bridges. The DVL is configured through its own web interface (Figure 4).

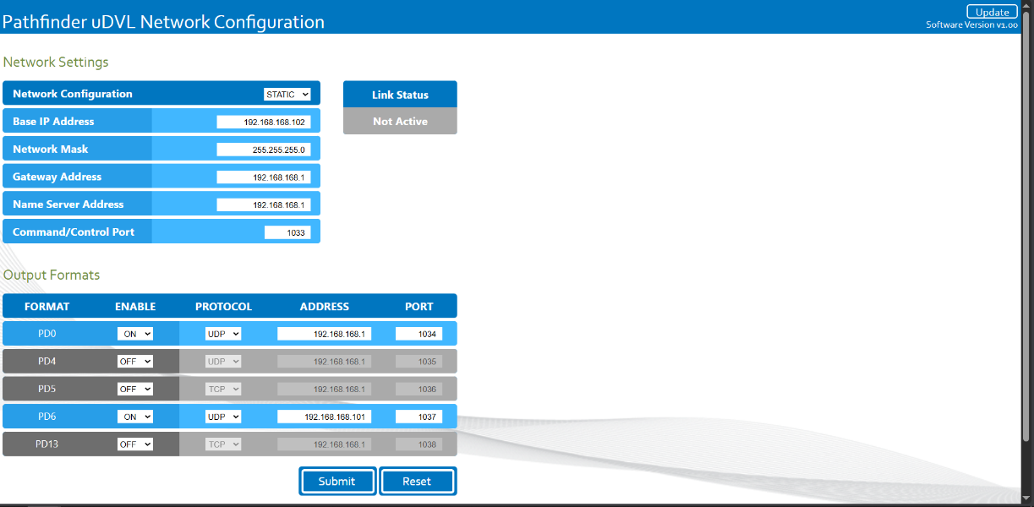
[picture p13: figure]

Figure 4 — DVL web configuration: static IP 192.168.168.102 and the enabled PD0 / PD6 UDP output formats.

## QGroundControl (QGC) Integration

The vehicle was connected to QGroundControl (QGC), a common open-source ground-control station, through a MAVLink bridge node. The bridge is plain Python on ROS 2 with no external MAVLink library, so it is easy to deploy and extend.

- Telemetry: The bridge streams four MAVLink messages to QGC, HEARTBEAT (1 Hz; vehicle alive and armed state), ATTITUDE (20 Hz; roll, pitch and yaw from the BNO055), GLOBAL_POSITION_INT (20 Hz; position and velocity derived from the DVL) and SYS_STATUS (20 Hz; battery, sensors and health).
- Commands: It translates QGC MANUAL_CONTROL (joystick) messages into motor PWM on /motor_data, so the vehicle can be flown directly from the QGC Fly view.

On the operator side the PC is placed on the vehicle subnet (192.168.168.100) and QGC is pointed at a UDP link to 192.168.168.101:14550.

## Guided Mode (Autonomous “Go-to-Location”)

Guided mode lets the operator click a point in QGC and have the vehicle navigate there autonomously, then hold position. It runs entirely on the UP Board, so the control link is only needed to send the target and to abort. This is the as-built form of the Autonomous Mission mode defined in the preliminary design; the three planned modes, Manual, Assisted and Autonomous Mission, correspond to the Manual, Stabilize and Guided modes used in this report.

When a target is received (as a NavSatFix on /guidance/goto_target), the guidance node computes the great-circle bearing and haversine distance from the current GPS fix to the target and drives the vehicle in three coordinated behaviours:

- Heading and transit: The vehicle yaws to the target bearing using the BNO055 heading, then drives forward, forward thrust is gated off until the heading is aligned, capped for safety, and ramped down as it approaches.
- Depth hold: The depth measured at engagement is captured and held on the vertical thrusters with a proportional law and a small dead-band, so the vehicle stays level en route. At the surface this keeps the verticals neutral, which is bench-safe.
- Loiter on arrival: Within a few metres of the target the vehicle does not stop and drift; it keeps pursuing the target gently and holding depth until the operator takes over.

The manoeuvre aborts safely, returning to Manual with neutral thrusters, on any joystick deflection, a switch to Manual mode, loss of the operator link (no input for several seconds), or an implausibly distant target.

## Acoustic (USBL) Control Link

To allow cable-free operation, an acoustic control path was built around a pair of Subsonus USBL modems. It mirrors the wired workflow, via a dedicated python script, The bridge carries compact telemetry and the full command set over the acoustic link; video is intentionally omitted, as it is not feasible over the limited acoustic bandwidth.

- Vehicle side: acoustic_bridge_node packages telemetry and unpacks commands over the modem link.
- Operator side: a small bridge program relays between QGC's MAVLink UDP and the acoustic packets, and annunciates link loss to the operator.

Both modems must be submerged to communicate. The modems are configured through their Ethernet web interface (Figure 5), where each unit is given a static address on its own subnet.

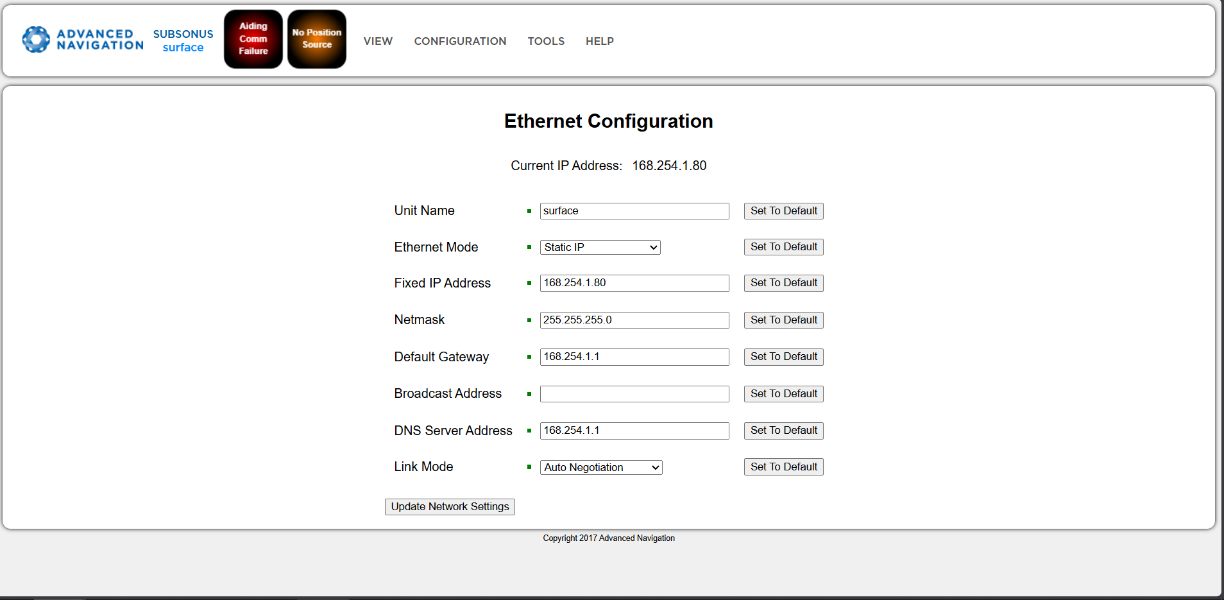
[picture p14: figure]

Figure 5 — Subsonus USBL Ethernet configuration (surface unit).

## Safety Systems

A central aim of this stage was for the vehicle to protect itself. Three independent safety mechanisms were implemented, all designed to remain effective even if the link is degraded or lost.

- Leak → auto-surface: On a confirmed leak the guidance node latches an emergency ascent that overrides every other mode, stopping lateral motion and driving the vertical thrusters up to the surface. It runs on the vehicle itself, so it works even if the link drops, and it alerts the operator with a repeated QGC warning.
- Link-loss failsafe: If the operator link goes quiet for more than a few seconds, the thrusters are commanded to neutral, so a lost connection cannot leave the vehicle driving away on its own.
- Attitude safety envelope: Commanded thrust is scaled back when pitch or roll become extreme, reducing the risk of the vehicle tumbling or losing controllability in an unstable attitude.

## Design Considerations

- Interoperability: Building on MAVLink and QGroundControl, with a dependency-free Python bridge, lets the vehicle be operated with standard, well-supported tooling and keeps the integration easy to extend (e.g. video, missions, parameter tuning).
- Separation of concerns: Real-time motor and sensor tasks run on the ESP32, while autonomy and telemetry run on the UP Board, placing deterministic control and higher-level computation each where it belongs.
- Autonomy on the vehicle: Guided navigation and the leak failsafe execute on-board, so they continue to work when the communication link is degraded or cut.
- Safety-first defaults: Failsafes fail toward the surface and toward neutral thrust, and the vehicle is motion-free at the surface, making bench and shallow-water testing safe.

# Simulation Verification (ROS 2 Gazebo)

## Vehicle CAD Model

A full 3D CAD model of the HAUV was built in Autodesk Fusion. It uses off-the-shelf watertight enclosures from Blue Robotics for the electronics and batteries, so those parts can simply be bought, while the rest of the vehicle, the frame, trays and mounts, is simple and can be fabricated easily. This model is the proof-of-concept design for the vehicle, and it was the basis for the Gazebo simulation.

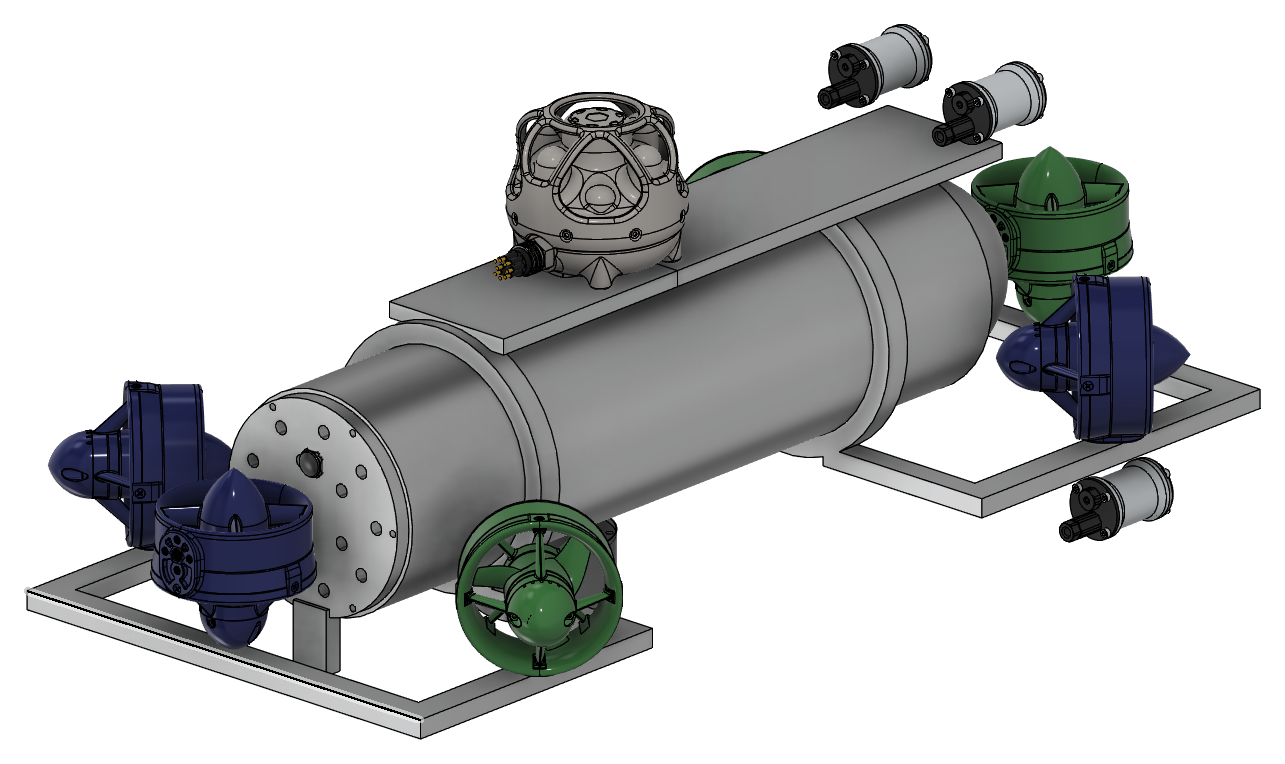
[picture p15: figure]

Figure 6 — 3D CAD model of the HAUV (Autodesk Fusion 360).

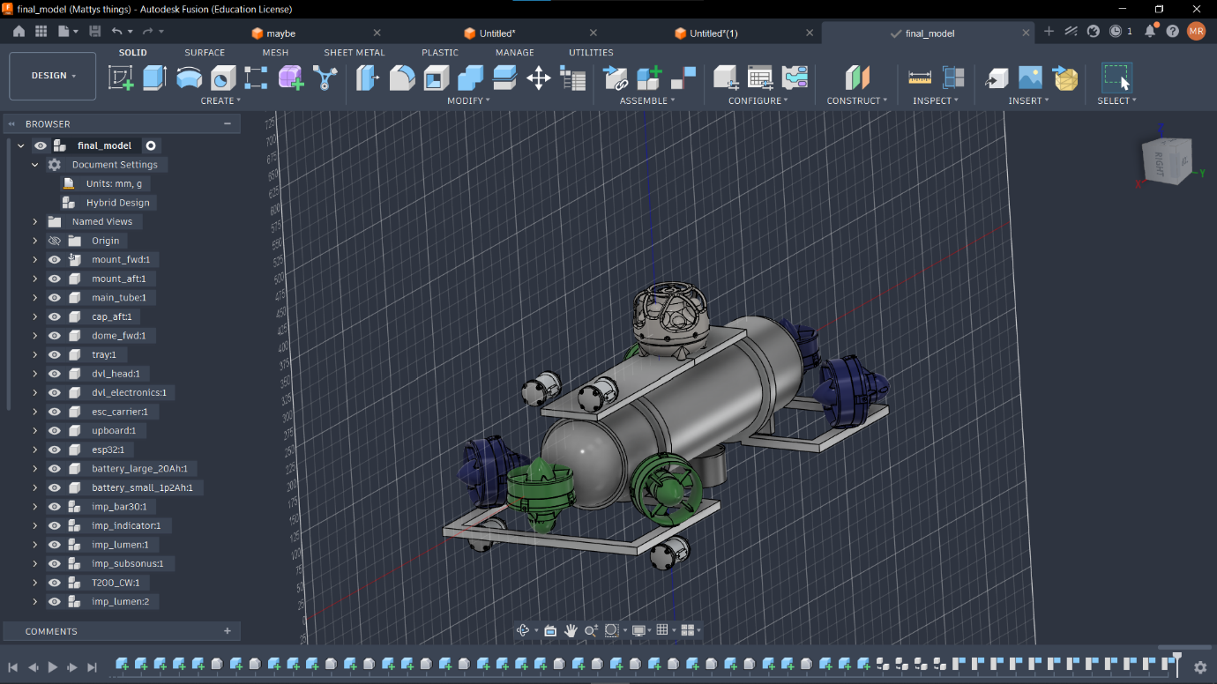
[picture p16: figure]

Figure 7 — The CAD assembly in Fusion 360, showing all the vehicle components.

Before any hardware testing, the control software was tested in a Gazebo simulation of the HAUV (the 5-inch, 13.6 kg hull). The same guidance_node that runs on the real vehicle was flown against the model: bridge nodes fed it simulated sensor data and turned its motor commands into thruster forces, so the code could not tell it was not on the real vehicle. A scripted pilot stood in for the operator, and every result below comes from recorded data.

The software was exercised across four scenarios, manual driving, depth hold, autonomous go-to-location and the leak failsafe, and of 24 automated checks, 23 passed. The single failure is deliberate and records a real defect in guidance_node (out-of-range joystick PWM) rather than a problem with the simulation.

## Manual Driving

Each stick axis was driven to full deflection in turn. Every command produced motion on its own axis with negligible cross-coupling: forward gave 0.85 m/s of surge, strafe reached 0.88 m/s to port, and a yaw command produced 65 °/s of rotation rather than a strafe, confirming the rear-thruster geometry is correct.

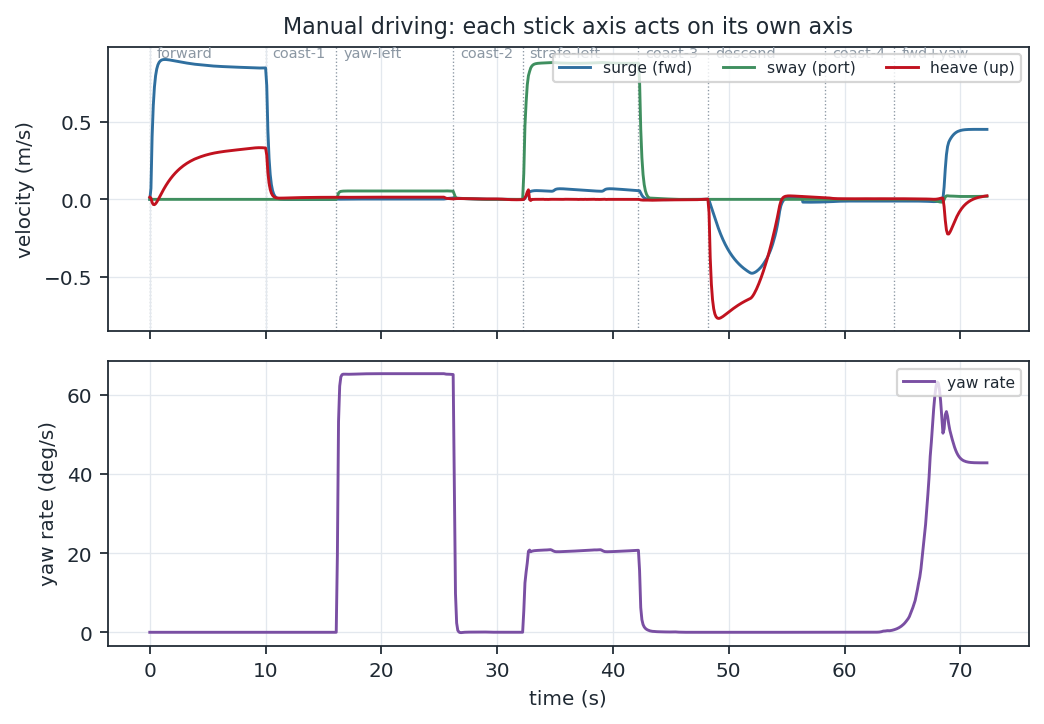
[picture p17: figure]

Figure 8 — Body-frame velocities and yaw rate through the manual sequence. Each command acts on its own axis.

## Depth Hold

Placed at 6 m and told to hold station, the vehicle isolated the vertical loop. Depth stayed within 0.30 m of the engage depth over 90 s, exactly the no-thrust deadband, and the tightest a deadbanded controller can hold, against the 0.90 m of buoyant rise that would have occurred with no control. Mean vertical-thruster output was 1493 µs, i.e. actively pushing down, confirming the depth-hold gain has the correct sign.

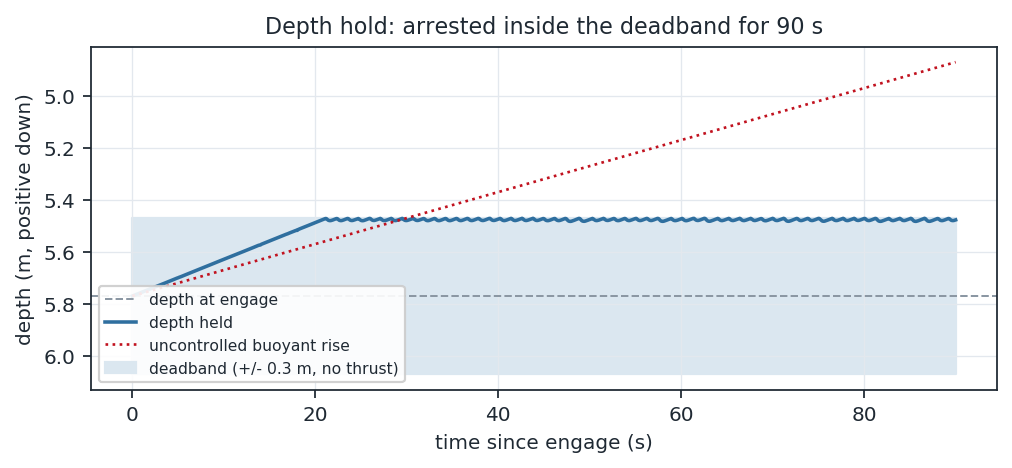
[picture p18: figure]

Figure 9 — Depth held inside the deadband over 90 s; the dotted line is the uncontrolled buoyant rise.

## Autonomous Go-to-Location

A target was placed 29.1 m away and astern. The vehicle turned the short way round, drove in, ramped down on approach and closed to 1.49 m in 57 s, with zero backtrack over the entire transit. Depth varied by only 0.32 m while under way, confirming that depth hold works in transit and not only at rest. On arrival the vehicle station-kept for 60 s without leaving the 4 m arrival radius, and a stick deflection returned it cleanly to manual with every motor at 1500 µs.

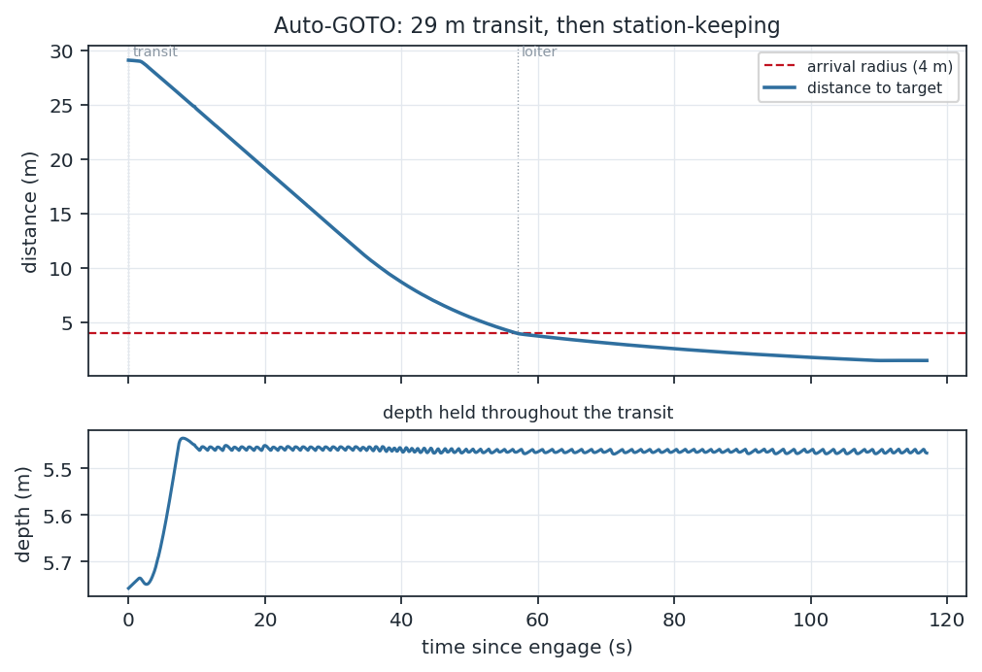
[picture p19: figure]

Figure 10 — Distance to target and depth: a 29 m transit in ~57 s, then station-keeping with depth held.

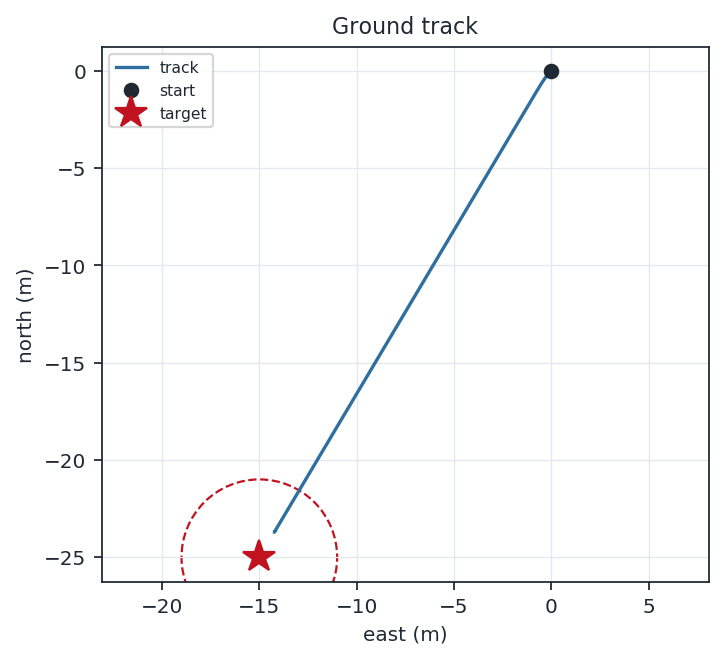
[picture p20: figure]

Figure 11 — Ground track in the north-east plane, closing inside the 4 m arrival radius.

## Leak Failsafe

A leak was asserted at 7.8 m depth. The failsafe latched after the required two consecutive wet samples and logged “LEAK DETECTED, auto-surfacing”. The horizontal thrusters went to exactly 1500 µs and the verticals to 1820 µs (the commanded 0.8 ascent) until the vehicle reached 0.08 m, whereupon thrust was released and it held at the surface; five seconds of dry readings then auto-cleared it back to manual. The ascent direction proved correct, the vehicle surfaced rather than dived.

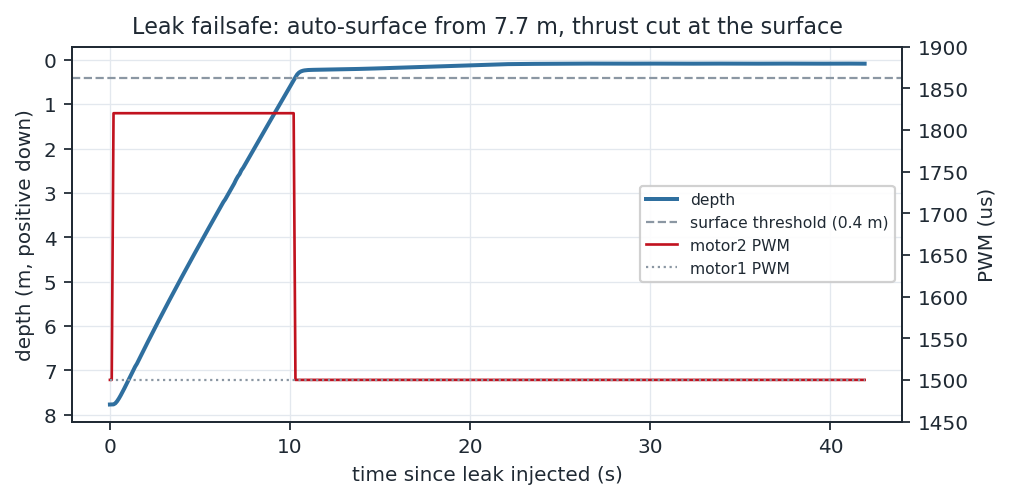
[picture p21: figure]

Figure 12 — Leak failsafe: auto-surface from 7.8 m, with thrust cut at the surface.

## The Simulated Environment

The figure below shows the hull holding depth in the simulated water column, 801 mm overall, with the vertical thrusters carried on outriggers, and visibility falls off with range by design, with fog applied from 3 m to 35 m.

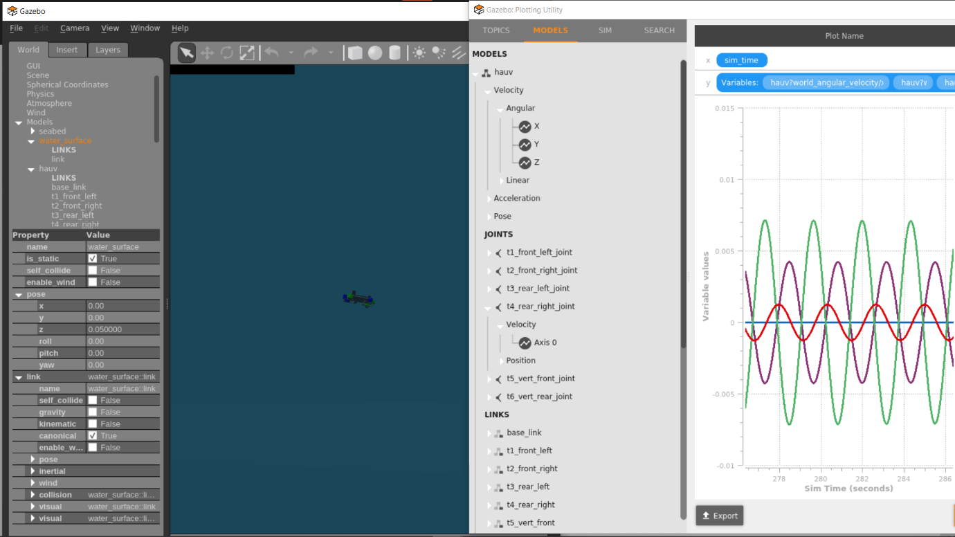
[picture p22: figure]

Figure 13 — HAUV simlulated in Gazebo with it's velocity graphs.

## Findings and Limitations

Flying the software surfaced one control-software defect. The joystick branch of the motor mixer does not clamp its PWM to the 1100–1900 µs range, full forward combined with full yaw produced 2183 µs, and the firmware silently drops out-of-range commands, which can freeze two of the four horizontal thrusters while turning and driving; this is the single deliberate failing check, fixed with a one-line clamp.

These results bound what can be concluded: drag is linear and isotropic, so the speeds are indicative rather than predictive; the water surface is a rigid slab; no DVL or USBL is simulated, so GOTO navigates on the synthesised GPS fix; and the verified control signs are the model's, not the hardware's.

# Final Acceptance Tests

This section describes the experiments used to validate the integrated system, the telemetry link, the sensors, the autonomous Guided mode, the safety failsafes and the acoustic channel. Testing was carried out in the laboratory and on the bench; full underwater testing remains for a future, water-resistant build.

The vehicle's live state was also visualised in RViz: its URDF model, driven by the real-time TF tree from the on-board sensors, gives a 3-D view of the HAUV's orientation and thruster layout during operation (Figure 14).

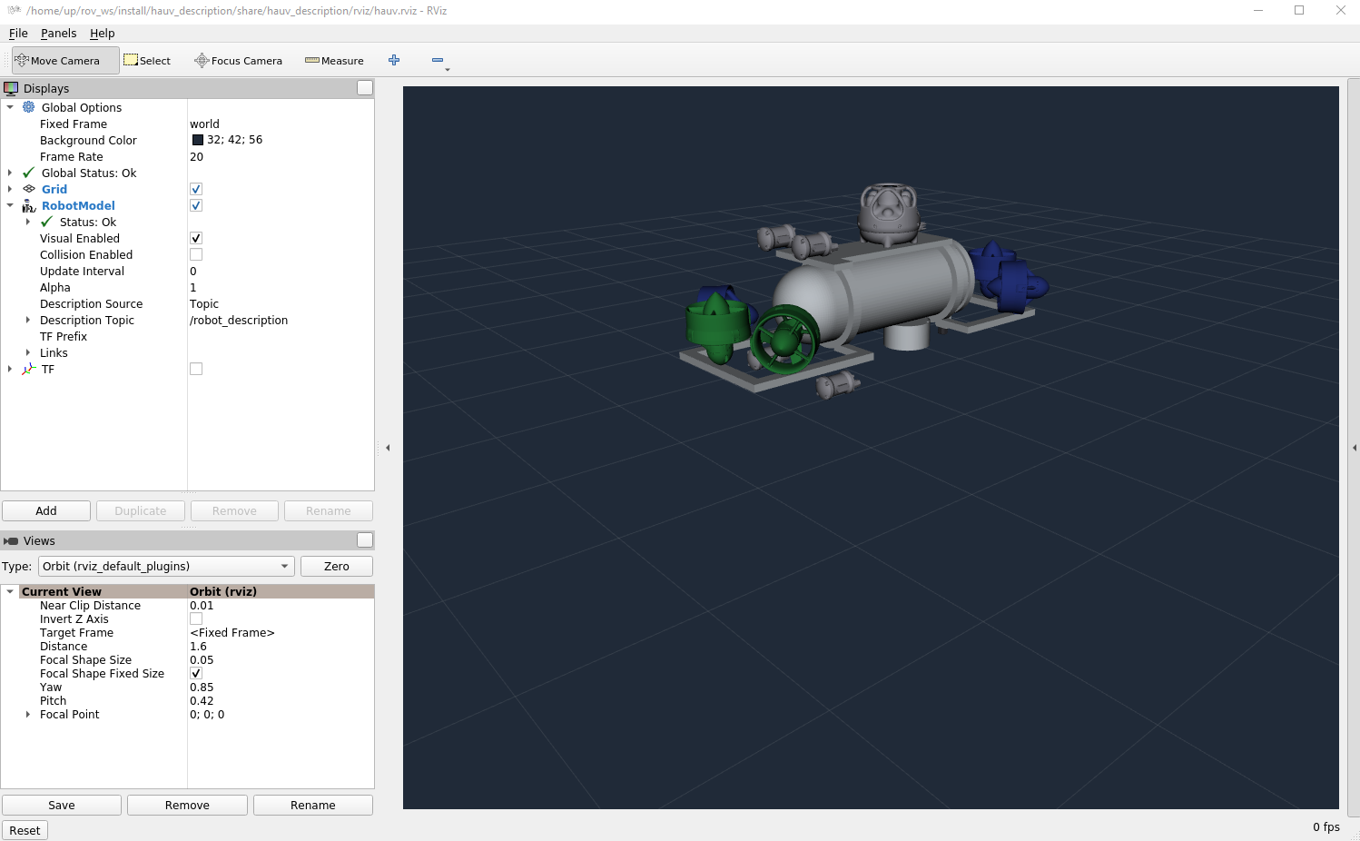
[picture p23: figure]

Figure 14 — Live RViz visualisation of the HAUV, driven by the vehicle's URDF model and real-time TF tree.

## 1. QGroundControl Telemetry and Control

- Telemetry: With QGC connected over Ethernet, the MAVLink Inspector confirmed all four message types arriving at their design rates, HEARTBEAT at ~1 Hz and ATTITUDE, GLOBAL_POSITION_INT and SYS_STATUS at ~20 Hz. The QGC attitude indicator tracked the BNO055 as the vehicle was tilted by hand.
- Control: Joystick input in the QGC Fly view was translated by the bridge into motor commands on /motor_data, and the thrusters responded in real time, confirming the command path QGC → bridge → guidance → ESP32 → motors.
- Auto-discovery: QGC connected without manual pairing, the bridge learned QGC's address from the first packet and replied to it.

## 2. System Health Check

The hauv.sh check command samples every sensor topic and reports OK / LOW / FAIL together with the measured rate, giving a one-command view of system integrity. A representative result showed the IMU, environmental and leak topics all reporting at ~22 Hz, while the DVL correctly reported FAIL out of water, expected behaviour, as the DVL needs water and a bottom to range against. This test doubles as a fast diagnostic: a genuinely missing sensor is flagged and pointed at its node.

## 3. Doppler Velocity Log

The DVL was configured through its web interface (network settings and enabled output formats) and its velocity output verified on the /dvl/velocity_data topic, confirming correct parsing and republishing by dvl_node for use by the guidance core and the telemetry bridges.

## 4. Autonomous Guided Mode (bench-safe)

- Navigation: On a QGC “Go-to-location” command the vehicle entered Guided mode, computed the distance and bearing from its GPS fix to the target, and yawed toward the bearing before driving forward, confirming the full command chain into calculate_goto_motor_speeds.
- Depth hold: Because the depth-hold law keeps the vertical thrusters neutral when the vehicle is at its engaged (surface) depth, the manoeuvre is motion-free vertically on the bench, allowing safe out-of-water testing.
- Aborts: Every abort path was verified to return the vehicle to Manual with motors neutral, any joystick deflection, a switch to Manual mode, a comms timeout, or a target beyond the maximum range.

## 5. Leak Auto-Surface Failsafe

The failsafe was exercised safely by injecting a simulated leak at the surface. The guidance log showed the expected sequence, the leak latching the emergency auto-surface (“LEAK DETECTED”) and, once the sensor read dry again, auto-recovering (“Leak cleared”). Because the vehicle was at the surface, the vertical thrusters stayed neutral, so the test was motion-free, and the emergency alert was raised in QGC.

## 6. Acoustic (USBL) Link

Over the acoustic bridge, QGC operated the vehicle using the compact telemetry packet, and loss of the acoustic link was annunciated to the operator. As the navigation runs on the UP Board, the acoustic link is only needed to send a target and to abort, not throughout the run, which keeps the untethered mode robust to intermittent acoustic conditions.

# Problems and Solutions

Several substantial engineering problems had to be solved during this stage, spanning software, sensors, communication and hardware reliability.

## 1. Broken sensor logic and cluttered ROS communication

- Problem: The inherited codebase had broken sensor logic and a cluttered set of ROS topics, which made the vehicle's state hard to trust and to debug.
- Solution: After building working proficiency in ROS 2, the codebase was refactored: the broken sensor logic was restored, unused topics were pruned, and a dedicated temperature topic was added new brand new adafruit BME sensor. This produced a clean, reliable data flow that the new autonomy and telemetry features could build on.

## 2. Running all sensors at once on a single I²C bus

- Problem: The sensors could not all be operated simultaneously, the initial wiring was limited to three devices, which was insufficient for the full sensor suite.
- Solution: A dedicated I²C breakout board was added, allowing the BNO055, BAR100 and BME280 to share the bus and operate together. A BMP280/BME280 hardware mismatch was also identified and the drivers updated and later relaced with a roer adafruit as it its i2c address couldn’t be realce and was identical to the bno.

## 3. Unreliable debugging and power during development

- Problem: An interfering LCD screen and an unstable battery supply made bench development unreliable.
- Solution: The LCD was replaced with a stable UART debug channel (a dedicated FTDI serial line), and the development setup was powered from a wall charger instead of the battery, giving a stable and repeatable bench environment.

## 4. Accurate underwater velocity

- Problem: Deriving velocity by integrating accelerations accumulates drift and is impractical for navigation.
- Solution: A dedicated I²C breakout board let the BNO055, BAR100 and BME280 share the bus. A BMP280/BME280 mismatch was corrected in the drivers, and the environmental sensor was later swapped for an Adafruit board after its fixed I²C address was found to clash with the BNO055.

## 5. MAVLink Bridge

- Problem: Building a MAVLink bridge that QGroundControl will accept is non-trivial, since QGroundControl is designed for aerial drones rather than underwater vehicles.
- Solution: The MAVLink bridge was written to present the vehicle as an ArduSub device, which unlocks QGroundControl's built-in underwater (submarine) capabilities.

## 6. Incompatible Python libraries

- Problem: The Subsonus and DVL Python libraries were incompatible with the HAUV's Python version.
- Solution: Bespoke scripts were written to communicate with the devices directly, reusing the relevant code from the vendor libraries. This removed the Python-version dependency and left the codebase cleaner and easier to maintain.

## 7. Persistent ESP32 lock-up

- Problem: The ESP32 would intermittently lock up, its indicator LED going solid while all sensor topics died, the moment the software stack started, taking every sensor down with it.
- Solution: Two root causes were found and fixed. A failing BAR100 depth sensor was pulling the I²C bus low and freezing the firmware on its first read (only after the micro-ROS agent connected); and the start-up script's reset pulse never actually reset this board, so it was swapped for an esptool hard reset, the only software reset it honours, letting the stack restart cleanly without a manual button press.

## 8. Work halted due to the Iran War

- Problem: From March to mid-July the war with Iran closed the campus and called me up for reserve duty, so lab work stopped for several months.
- Solution: While the lab was closed I worked on the parts that did not need it, the Gazebo simulation and the CAD model and returned to on-site work once the campus reopened.

# Recommendations and Conclusions

## Summary of Work

This stage advanced the HAUV from a bench prototype into an operable, autonomous and self-protecting vehicle. It was integrated with QGroundControl through a custom MAVLink bridge; an autonomous Guided (go-to-location) mode was added; an untethered acoustic (USBL) control channel was implemented; a Doppler Velocity Log was integrated for velocity measurement; and on-board leak, link-loss and attitude failsafes were built. These capabilities rest on substantial systems-integration and reliability work: refactoring the codebase, building a custom I²C breakout board, and diagnosing and resolving a persistent ESP32 lock-up. As in the earlier stage, the vehicle has not yet been deployed in a water-resistant enclosure, so live underwater testing remains incomplete.

## Comparison of Results with Project Goals

The four project goals were largely met in the laboratory and on the bench. QGC connects automatically and displays all four telemetry streams at their target rates, with joystick input driving the thrusters (Goal 1). Guided mode computes the bearing and distance to a selected target and drives toward it with depth hold and station-keeping, aborting safely on operator input or link loss (Goal 2). The acoustic bridge carries the same telemetry and commands without a cable (Goal 3). The leak auto-surface, link-loss failsafe and single-command operation were demonstrated on the bench (Goal 4). What remains unverified is the vehicle's behaviour in the water: two navigation sign conventions (yaw and depth direction) are one-line flips to confirm during the first in-water run, and full underwater performance is still to be validated.

## Advantages and Disadvantages

Advantages:

- Operable with standard, off-the-shelf tools (QGroundControl over MAVLink).
- Two control links, a wired tether with full telemetry and video, and an untethered acoustic link.
- On-board autonomy and failsafes that keep working when the operator link is degraded or cut.
- Modular, refactored software with a single-command operating and diagnostics tool.

Disadvantages:

- Not yet water-resistant, so real-world underwater applicability is unverified.
- Surface station-keeping is only as tight as the GPS fix; underwater USBL positioning would be tighter.
- The acoustic link carries only compact telemetry and no video.

## Recommendations for Future Work

- Water-resistant enclosure and live underwater trials to validate navigation, depth hold and the failsafes in the water, including the two sign-convention checks.
- Underwater positioning: feed USBL/DVL-based position into the navigation core (replacing the surface-GPS origin) for tight underwater station-keeping.
- Mission planning: extend the MAVLink bridge with waypoint missions and parameter tuning through QGC.
- A two-LED status subsystem and a power-cycle-capable hardware watchdog for the ESP32 to enable automatic recovery from a lock-up.
- Video or richer telemetry over the acoustic path through improved compression.

## Conclusions

This project turned the HAUV into a vehicle that can be flown from a standard ground station over either a wired or a wireless link, navigate autonomously to a target, and protect itself in a fault. Combined with a refactored and more reliable software base, the platform is now a solid foundation for the remaining step: a water-resistant build and live underwater validation.

# References

1. Ewart, T. E., “Observations from Straight Line Isobaric Runs of SPURV,” Joint Oceanography Assembly, Edinburgh (UK), 13 Sep. 1976.
2. Blue Robotics, “BlueROV2 – Underwater ROV.” [Online]. Available: https://bluerobotics.com/store/rov/bluerov2/ (accessed Nov. 15, 2024).
3. J. J. Leonard and A. Bahr, “Autonomous Underwater Vehicle Navigation,” in Springer Handbook of Ocean Engineering, 2016, pp. 341–358.
4. R. V. Aroca and L. M. G. Gonçalves, “Towards green data centers: A comparison of x86 and ARM architectures power efficiency,” Journal of Parallel and Distributed Computing, vol. 72, no. 12, pp. 1770–1780, 2012.
5. G. Andreescu, C.-D. Căleanu and S. Nanu, “Simulation environment for mobile robots testing using ROS and Gazebo,” in Proc. 20th Int. Conf. System Theory, Control and Computing (ICSTCC), Sinaia, Romania, 2016, pp. 329–334.
6. C. Ramirez-Atencia and D. Camacho, “Extending QGroundControl for Automated Mission Planning of UAVs,” Sensors, vol. 18, no. 7, p. 2339, 2018.

# Appendices

## Appendix A — Operating the vehicle (hauv.sh)

The entire software stack is run and inspected through a single management script on the UP Board.

Command | Action
./hauv.sh start [--ethernet | --acoustic] | Start the full stack (default: Ethernet / tethered)
./hauv.sh stop | Stop everything
./hauv.sh restart [--ethernet | --acoustic] | Stop, then start
./hauv.sh check | Sample every sensor topic and report OK / LOW / FAIL with rate
./hauv.sh status | List the running node sessions
./hauv.sh topics | List live topics with their short names
./hauv.sh echo <NAME|/topic> | Stream one topic's values (e.g. echo DEPTH)
./hauv.sh view <node> | Attach to a node's log (Ctrl-A D to detach)

Table A1, hauv.sh operating commands

## Appendix B — QGC MAVLink telemetry messages

Message | Rate | Source | Fields
HEARTBEAT | 1 Hz | Bridge | Vehicle type, armed state, mode
ATTITUDE | 20 Hz | BNO055 | Roll, pitch, yaw
GLOBAL_POSITION_INT | 20 Hz | DVL | Position, velocity, heading
SYS_STATUS | 20 Hz | Sensors | Battery, sensor health, error counts
MANUAL_CONTROL (in) | event | QGC | Joystick axes → motor PWM on /motor_data

Table B1, MAVLink messages exchanged with QGroundControl

## Appendix C — Connecting QGroundControl

Over Ethernet (normal): set the operator PC to 192.168.168.100 (netmask 255.255.255.0), verify with ping 192.168.168.101, then add a UDP comm link to 192.168.168.101:14550. Turn QGC's UDP AutoConnect off so it does not grab the wrong endpoint.

Over acoustic (untethered): with both Subsonus modems in the water, start the vehicle with ./hauv.sh start --acoustic, run one instance of the PC-side acoustic bridge, and point QGC at a UDP link to 127.0.0.1:14551. Telemetry is compact and there is no video on the acoustic link.

## Appendix D — HAUV Operator's Manual

HAUV, Hybrid Underwater Vehicle, Operator's Manual

How to set up, drive and look after the HAUV

Draft v1.0, 19 July 2026

This manual is written in simple language on purpose. Read Chapter 2 (Safety) before you touch the vehicle. Proprietary document, do not share outside the team.

## 1 About the HAUV

### 1.1 What the HAUV is

The HAUV is a small underwater robot. You drive it from a laptop on the shore or on a boat. It can also drive itself to a point on the map. In simple words:

- You look at a screen. The screen shows a map, a video picture and numbers.
- You hold a game controller. You push the sticks. The robot moves.
- If you want, you click a point on the map. The robot swims there by itself.

### 1.2 The two computers inside

The HAUV has two computers. They do different jobs. It helps to know which one does what when something goes wrong.

Computer | What it does
UP Board | The “brain”. It thinks. It talks to your laptop, reads the GPS and the DVL, decides where to go, and runs the safety rules.
ESP32 | The “muscles”. It turns the motors, switches the lights, and reads the depth sensor, the compass and the leak sensor.

The two computers talk to each other over a small cable inside the vehicle. If that link breaks, the green light on the ESP32 goes off (see Chapter 10).

### 1.3 The main parts

Figure 1.1 shows the vehicle with the main parts numbered. The numbers match the table below.

# | Part | What it is for

1 | Subsonus (USBL modem) | Talks to the surface with sound, so the vehicle can be controlled with no cable.
2 | Electronics tray | Holds the two computers and the boards. See Section 1.4.
3 | Lights | Two sets of lamps. You switch them from the controller.
4 | Thrusters | The propellers that move the vehicle.
5 | Camera | Sends the live picture to your screen.
6 | DVL | Measures speed over the sea floor.

### 1.4 Inside the vehicle — the electronics

Figure 1.2 shows the electronics tray with the main boards numbered. You do not need to touch these to drive the vehicle. It helps to know where they are when something stops working.

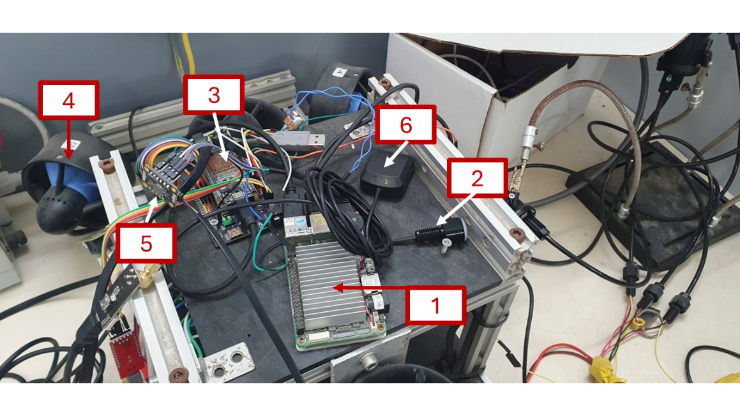
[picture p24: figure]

Figure 1.2: The electronics tray. The numbers match the table below.

# | Part | What it is for

1 | UP Board | The “brain”, the board with the big metal heatsink.
2 | Indicator light | The status light. Tells you if the two computers are talking. See Chapter 10.
3 | ESP32 | The “muscles”, the board with the coloured wires.
4 | Thruster | One of the propellers.
5 | I2C connector | Goes to the temperature sensor.
6 | GPS antenna | The small black square marked GPS. Gives the position on the surface.

### 1.5 What you need before you start

1. The HAUV vehicle, charged.

2. A laptop with QGroundControl installed. We call it QGC.

3. An Xbox-style game controller, plugged into the laptop.

4. A network cable (for the cable mode), or the two Subsonus modems (for the sound mode).

5. A bucket of fresh water for washing the vehicle after the dive.

## 2 Safety First

Warning! The propellers can cut your fingers. They can start turning at any time when the vehicle is powered on. Keep hands, hair and clothes away.

### 2.1 The golden rules

1. Never stand next to the propellers when the vehicle is powered on.

2. Always power the vehicle off before you carry it.

3. Do not open the vehicle when it is wet. Dry the outside first.

4. Do not run the thrusters in air for a long time. They need water to stay cool.

5. If you see water inside, stop. Take the vehicle out. Dry it. Find the leak.

6. Do not charge a battery that is hot or damaged.

7. One person drives. One person watches the vehicle and the cable.

### 2.2 Before every dive

1. Look at the vehicle. Are all screws in place? Is anything broken?

2. Check that all plugs are pushed in fully.

3. Check that the lid is closed and tight.

4. Check the battery is charged.

5. Check the propellers turn freely and nothing is stuck in them.

Note. If anything looks wrong, do not dive. It is always cheaper to fix it on the table than at the bottom of the sea.

## 3 Network Setup

The laptop, the vehicle and the sensors all talk over a network. Each one has its own address. The addresses must be correct or nothing will connect.

### 3.1 The addresses

Device | Address | Notes
Your laptop (QGC) | 192.168.168.100 | You set this by hand.
UP Board (the brain) | 192.168.168.101 | Fixed. Do not change.
DVL | 192.168.168.102 | Fixed. Do not change.
Subsonus on the surface | 168.254.1.80 | Only for the sound mode.

### 3.2 Setting your laptop address

1. Open Network settings on your laptop.

2. Find the wired (Ethernet) connection.

3. Choose Manual / Static address.

4. Type address 192.168.168.100 and mask 255.255.255.0.

5. Save.

Tip. To test it, open a terminal and type ping 192.168.168.101. If you get replies, the network is good. If you get nothing, check the cable and the address.

## 4 Connecting QGroundControl

There are two ways to talk to the HAUV:

Way | When to use it
Cable (Ethernet) | Normal work. Fast. You get video and all the numbers.
Sound (Acoustic / USBL) | When the vehicle is under water with no cable. Slow. No video. Only the important numbers.

### 4.1 Connecting with a cable (Ethernet)

This is the normal way. Do this first when you are learning.

1. Plug the network cable between the laptop and the vehicle.

2. Power the vehicle on.

3. Open QGroundControl on the laptop.

4. Click the Q logo in the top left corner, then Application Settings.

5. Choose Comm Links on the left.

6. Click Add.

7. Fill in the window: Name: HAUV UP Board; Type: UDP; Port: 14550; Server Address: 192.168.168.101:14550, then press Add Server.

8. Click Save.

9. Select HAUV UP Board in the list and click Connect.

Note. Turn AutoConnect to UDP off on the General page. If you leave it on, QGC may connect to the wrong thing and the vehicle will look dead. When it works you will see the vehicle appear on the map and the numbers at the bottom of the screen will start moving.

### 4.2 Connecting with sound (Acoustic / USBL)

Use this when the vehicle is under water and there is no cable. It is slower. You will not get video. You need two Subsonus modems: one on the surface (in the water, next to you) and one on the vehicle.

1. Put the surface modem in the water. It must be in the water to work.

2. Power both modems on.

3. Open the surface modem page in a web browser. Check the settings match Figure 4.2 (address 168.254.1.80).

4. On the vehicle, start the system in sound mode (see Section 5.3).

5. On the laptop, run the bridge program once: python tools/acoustic_qgc_bridge.py

6. In QGC, connect to 127.0.0.1:14551.

Figure 4.2: The Subsonus surface unit settings page. The address must be 168.254.1.80.

Warning! Run only one copy of the bridge program. If you start it twice, the commands fight each other and the vehicle behaves strangely.

Warning! Both modems must be in the water. Out of the water they cannot hear each other and you will see ACOUSTIC LINK LOST on the screen.

### 4.3 DVL settings (for reference only)

The DVL is already set up. You do not normally touch it. Figure 4.3 shows the correct settings, in case you ever need to check them.

Figure 4.3: DVL network page. Address 192.168.168.102, command port 1033, outputs PD0 and PD6 switched ON.

## 5 Starting the HAUV

### 5.1 The batteries

The HAUV runs on two 12 V lithium battery packs, shown in Figure 5.1. One pack feeds the computers, the other feeds the thrusters. The thick red and black wires join them to the vehicle with yellow plugs.

Figure 5.1: The two 12 V battery packs and how they connect. Red is plus (+), black is minus (–). The small green board is the voltage converter that drops 12 V down for the electronics.

Connecting a battery:

1. Check the vehicle is switched off first.

2. Match the colours: red to red, black to black.

3. Push the yellow plug straight in until it clicks. Do not force it sideways.

4. Check nothing is loose and no bare metal is showing.

Warning! Never join red to black. A short circuit makes a big spark, ruins the battery and can start a fire.

Warning! Do not charge a battery that is hot, swollen or damaged. Do not leave batteries charging without somebody nearby.

Note. Charge both packs after every dive. A pack left flat for a long time can be damaged for good.

### 5.2 Power on

1. Check Chapter 2 again. Hands away from the propellers.

2. Switch the vehicle on.

3. Wait about 30 seconds. The computers need time to wake up.

### 5.3 Starting the software

All the software is started with one tool called hauv.sh. You run it on the UP Board (the vehicle's brain), through a terminal.

Command | What it does
./hauv.sh start | Starts everything, cable mode. This is the normal one.
./hauv.sh start --acoustic | Starts everything, sound mode (no cable).
./hauv.sh stop | Stops everything.
./hauv.sh restart | Stops, then starts again.
./hauv.sh check | Tests every sensor and says OK or FAIL.
./hauv.sh status | Shows what is running.
./hauv.sh topics | Lists the live data channels.
./hauv.sh echo DEPTH | Shows live values, for example the depth.
./hauv.sh view mavlink | Opens the log of one program. Press Ctrl+A then D to leave.
./hauv.sh help | Shows help and the short names.

### 5.4 Check everything works

Before you put the vehicle in the water, run ./hauv.sh check. It tests each sensor for a few seconds and prints OK, LOW or FAIL.

Result | Meaning
OK | Good. Nothing to do.
LOW | The sensor works but sends data slowly. Usually still fine.
FAIL | No data at all. Fix this before diving.
-- | This sensor only sends data sometimes. Not a problem.

Note. The DVL will say FAIL when the vehicle is out of the water. This is normal. The DVL needs water and a sea floor to see. It will work once you are in the water.

## 6 Reading the Screen

The main QGC screen is called the Fly View. This is what you look at while driving.

### 6.1 The parts of the screen

Where | What it shows
Middle | The map. The small vehicle symbol is your HAUV.
Top, yellow or red bar | Warning messages. Read these. See Section 6.3.
Bottom left | The camera picture. Says “WAITING FOR VIDEO” if there is none.
Bottom right | The numbers: depth, roll, temperature, speed, position, time.
Far bottom right | The compass. Shows which way the vehicle points.
Left side | Buttons: Land, Return, Pause, Actions.
Top right | Video record and photo buttons, and the settings gear.

### 6.2 The numbers you must watch

Number | Why it matters
Depth | How deep you are, in metres. Watch this all the time.
Roll | How much the vehicle is leaning. A big number means it is tipping over.
Ground Speed | How fast you are moving.
Latitude / Longitude | Where you are on the map (surface only).
Temperature | The water temperature.

### 6.3 Warning messages

Messages appear in a coloured bar at the top of the screen. Red and yellow ones are important.

Message | What to do
LEAK! Auto-surfacing | Most serious. Water is inside. The vehicle is already swimming up by itself. Get it out of the water. See Section 9.1.
ACOUSTIC LINK LOST | The sound link stopped. Check both modems are in the water and powered. See Chapter 12.
FAIL: ... | A sensor stopped working. The name after FAIL is the sensor.

Note. The leak message repeats every 3 seconds while the leak is there, so you cannot miss it.

## 7 Driving the HAUV

### 7.1 The controller

Hold the controller with both hands. The two sticks do the moving.

# | Control | What it does on the HAUV

3 | Left stick | Up / down: move forward and backward. Left / right: slide sideways (crab). The nose keeps pointing the same way.
1 | Right stick | Left / right: turn left and right. Up / down: go up and down in the water.
A | A button | Switch one set of lights on and off.
B | B button | Switch the other set of lights on and off.
5 | LB shoulder | Tilt the camera up.
10 | RB shoulder | Tilt the camera down. (This button also switches the mode.)

The parts not used for driving are: 2 (D-pad), 4 (Back), 6 and 9 (the two triggers), 7 (Xbox button), 8 (Start), and the X and Y buttons.

Tip. Push the sticks gently. Small movements are enough. The vehicle is heavy and keeps moving after you let go.

### 7.2 Your first drive

1. Put the vehicle in the water. Hold it until you are ready.

2. Check the screen. The depth should be near 0.

3. Push the left stick forward a little. The vehicle should move forward.

4. Pull it back. The vehicle should stop and go back.

5. Turn with the right stick. Watch the compass move.

6. Push the right stick down a little to go deeper. Watch the depth number grow.

Warning! Always know where the vehicle is. If you cannot see it and the screen is frozen, stop and bring it back.

## 8 Flight Modes

The vehicle has three modes. You change them in QGC, at the top of the screen.

### 8.1 Manual

You control everything with the controller. The vehicle does only what you tell it. Use this most of the time.

### 8.2 Stabilize

The vehicle tries to stay level by itself. You still drive it. Use this if the vehicle is rolling or tipping too much.

### 8.3 Guided — “Go to location”

The vehicle drives itself to a point you choose on the map. It keeps its depth on the way, and when it arrives it stays there instead of drifting away.

How to use it:

1. Make sure the vehicle has a GPS position (it must be on the surface).

2. On the map, click the place you want to go.

3. Choose Go to location.

4. The vehicle turns towards the point, then swims to it.

5. When it arrives, it stays there and holds its position and depth.

How to stop it (any of these work): move any stick on the controller; change the mode to Manual in QGC; or if the link is lost for 5 seconds, the vehicle stops by itself.

Warning! This only works on the surface for now, because it uses GPS. Under water there is no GPS.

## 9 Safety Features

These work by themselves. You do not switch them on.

### 9.1 Leak — the vehicle swims up by itself

If water gets inside, the leak sensor sees it. Then: the vehicle stops all sideways movement; it drives its up/down thrusters to go up to the surface; it stays on the surface; and your screen shows LEAK! Auto-surfacing in red, again and again.

This ignores everything else. Even if you are driving, or the vehicle is going to a point by itself, the leak wins and the vehicle goes up.

What you must do: do not fight it, let it come up; take the vehicle out of the water; dry the outside, then open it and find the water; do not dive again until you find why water came in.

Note. This works even if the cable or the sound link is broken. The decision is made inside the vehicle, not on your laptop.

Note. When the sensor is dry again for 5 seconds, the vehicle gives control back to you automatically. If the sensor stays wet, it stays on the surface, that is on purpose.

### 9.2 Lost control link

If the vehicle stops hearing your controller for about 1.5 seconds, it sets all thrusters to stop. It will not keep driving away with the last command.

## 10 Indicator Lights

There is a small green light on the electronics board inside the vehicle. It tells you if the two computers are talking to each other.

Green light | Meaning
On, steady | Good. The two computers are talking. Sensors and motors work.
Off | Bad. They are not talking. The motors will not answer. See Chapter 12.

Note. Just after you switch the vehicle on, the green light is on for a short time before the connection is really made. Wait about 30 seconds before you trust it.

## 11 After the Dive

1. Bring the vehicle out of the water. Two people if it is heavy.

2. Switch the vehicle off.

3. Wash the outside with fresh water. Salt water eats metal.

4. Pay attention to the propellers. Remove weed, sand and plastic.

5. Dry the vehicle with a cloth.

6. Only when it is dry outside, open it and check for water inside.

7. Charge the battery.

8. Copy any recorded data off the vehicle.

Warning! Never put the vehicle away wet or with a flat battery.

## 12 Troubleshooting

### 12.1 Common problems

Problem | What to try
QGC does not connect | 1. Check the network cable. 2. Check your laptop address is 192.168.168.100. 3. ping 192.168.168.101. 4. Check the link settings match the QGC Edit-Link window. 5. Turn AutoConnect UDP off in QGC.
Vehicle shows on screen but nothing moves | The two computers are not talking. Check the green light (Chapter 10). Restart with ./hauv.sh restart.
No video picture | Video only works over the cable, never over sound. Check the cable mode is running.
DVL says FAIL | Normal out of the water. If it still fails in the water, check the DVL settings.
ACOUSTIC LINK LOST | 1. Both modems must be in the water. 2. Check both are powered. 3. Check only one bridge program is running on the laptop. 4. Check the surface modem address (168.254.1.80).
Some sensors say FAIL | Run ./hauv.sh check to see which. Restart with ./hauv.sh restart. If it still fails, the sensor or its plug is bad.
Vehicle drifts away in Go to location | The GPS is only accurate to a few metres. This is normal. Take manual control if you need to be exact.
Vehicle keeps swimming up and will not stop | This is the leak failsafe. There is water inside. See Section 9.1. Get it out of the water.

### 12.2 Useful checks

Command | Use it to
./hauv.sh check | See which sensors are alive.
./hauv.sh status | See which programs are running.
./hauv.sh echo DEPTH | Watch the depth value live.
./hauv.sh echo LEAK | Check the leak sensor (0 = dry, 1 = water).
./hauv.sh view guidance | Read the messages from the driving program.
./hauv.sh restart | The general “switch it off and on again”.

Tip. If you are lost, ./hauv.sh restart fixes most software problems. It does not fix broken cables or wet electronics.

## Appendix E — Project Timeline

The project was carried out by a single student across five phases, from initial design through validation. The planned timeline was as follows.

### Phase 1 — Initialisation and Design (October–December 2025)

- Define the system requirements.
- Review the code and components available in the lab.
- Learn the ROS framework.
- Milestone, submission of the Preliminary Design Review (PDR).

### Phase 2 — Simulation and Physical Setup (December 2025–January 2026)

- Set up the software development environment in Linux.
- Learn QGroundControl as the communication framework.
- Implement basic control and operation in the simulation.

### Phase 3 — Core Development (January–March 2026)

- Develop the drivers and integrate the sensors.
- Develop autonomous navigation with sensor fusion.
- Integrate the system with QGroundControl for operator control.
- Milestone, readiness of the simulation.

### Phase 4 — Hardware Integration and Testing (March–May 2026)

- Finish assembling the electronic stack.
- Dry-test the communication between the HAUV and QGroundControl.
- Milestone, readiness of the hardware.

### Phase 5 — Validation and Final Testing (June–July 2026)

- Wet testing in a controlled environment.
- Execute all three modes of control.
- Write the final report.
- Milestone, final project presentation and demonstration of the POC.

## Appendix F — Budget Estimation

The budget estimate covers the critical hardware components required for the HAUV proof of concept. All software used is open-source, so no software expenses are incurred, and a 10% contingency was allocated for unforeseen costs. The total estimated budget is USD 16,583.

Item | Qty | Unit Price | Subtotal | Notes
Remotely Operated Vehicle | 1 | $4,900 | $4,900 | Blue Robotics BlueROV2
Doppler Velocity Log (DVL) | 1 | $8,000 | $8,000 | Teledyne Pathfinder OEM
Thrusters | 6 | $200 | $1,200 | Blue Robotics T200
Electronic Speed Controllers | 6 | $38 | $228 | Blue Robotics Basic ESC
Lights | 2 | $160 | $320 | Blue Robotics Lumen Subsea Light
Ethernet Switch | 1 | $175 | $175 | Blue Robotics
UP Board | 1 | $100 | $100 | Main processing unit
Camera | 1 | $100 | $100 | Blue Robotics Low-Light Camera
Beacon | 1 | $80 | $80 | Blue Robotics
Pan-Tilt Servo | 1 | $64 | $64 | Blue Robotics Camera Tilt Mount
Frames | 1 | $50 | $50 | Aluminium profiles
Leak Sensor | 1 | $35 | $35 | Blue Robotics SOS Leak Sensor
Battery 2 (120,000 mAh) | 1 | $31 | $31 | For motors and lights
ESP32 WROOM & 38-Pin Expansion Board | 1 | $30 | $30 | Real-time microcontroller with additional I/O
Battery 1 (30,000 mAh) | 1 | $25 | $25 | For UP Board, DVL and other components
Indicator | 1 | $15 | $15 | Blue Robotics
Miscellaneous | – | – | $100 | Cables, connectors, etc.
Contingency (10%) | – | – | $1,130 | Covers unexpected expenses
Total Budget | | | $16,583

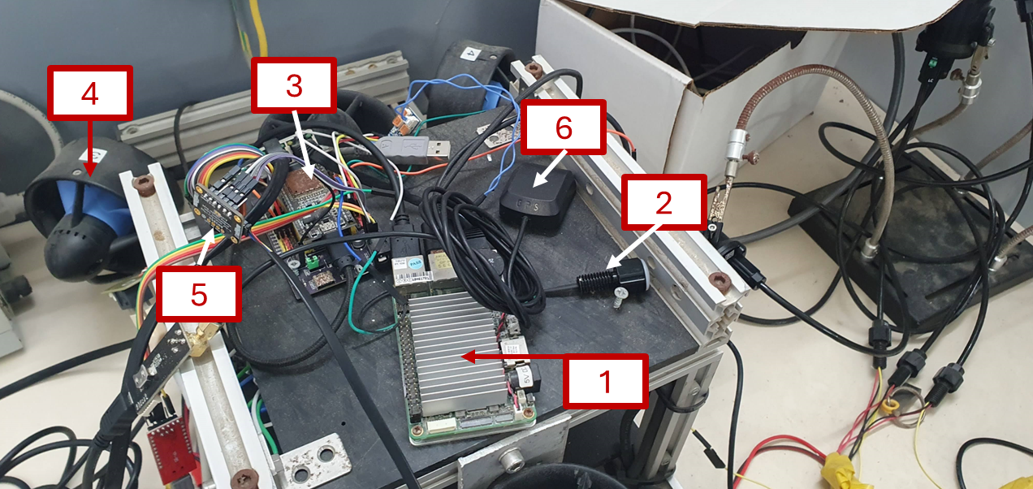
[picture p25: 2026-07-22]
pics/electronics numbered.png

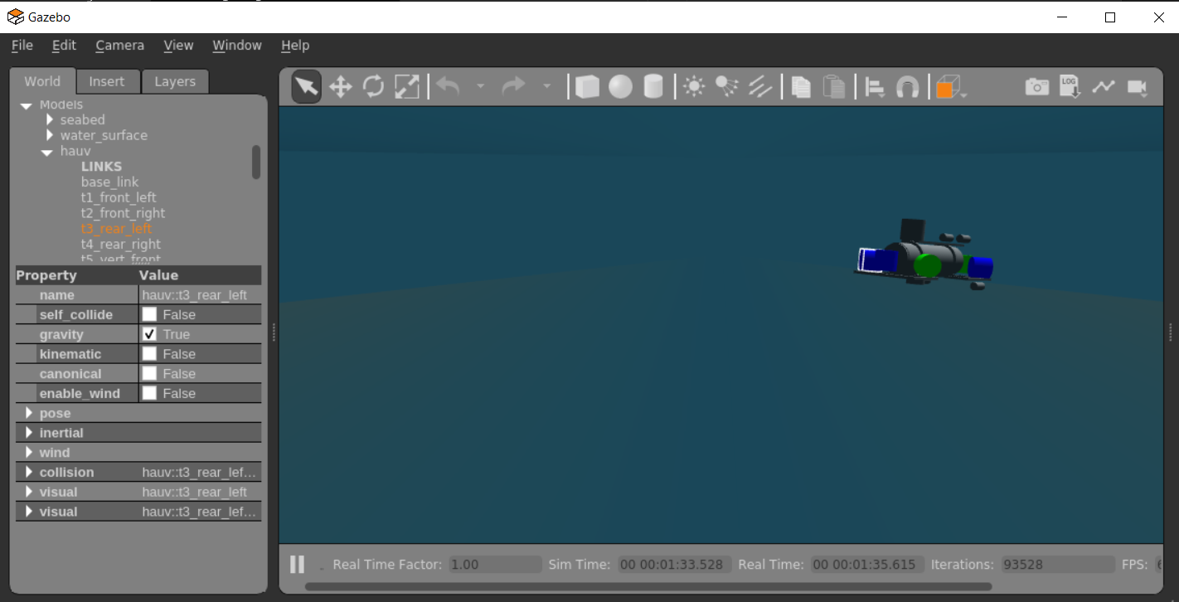
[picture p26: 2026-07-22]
pics/gazebo ui.png

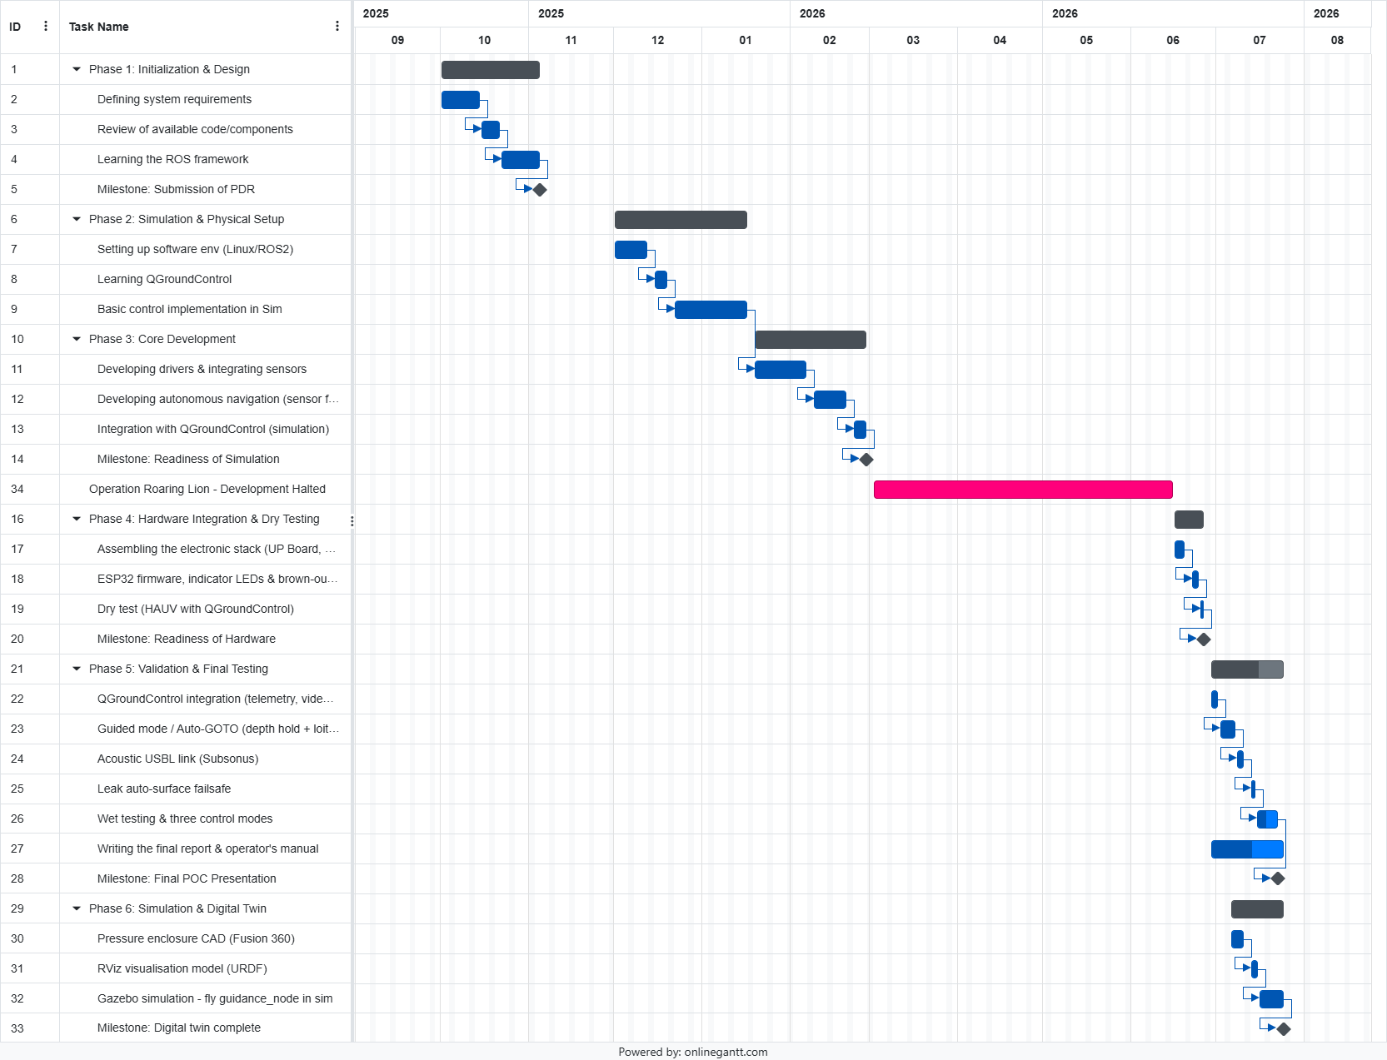
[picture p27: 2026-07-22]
docs/Gantt.png

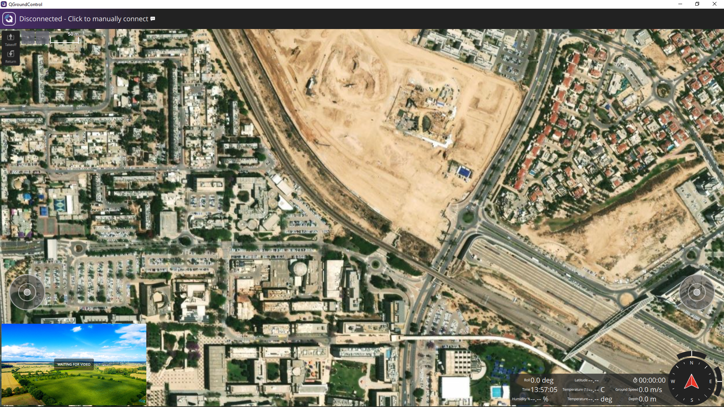
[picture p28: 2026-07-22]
pics/qgc init.png

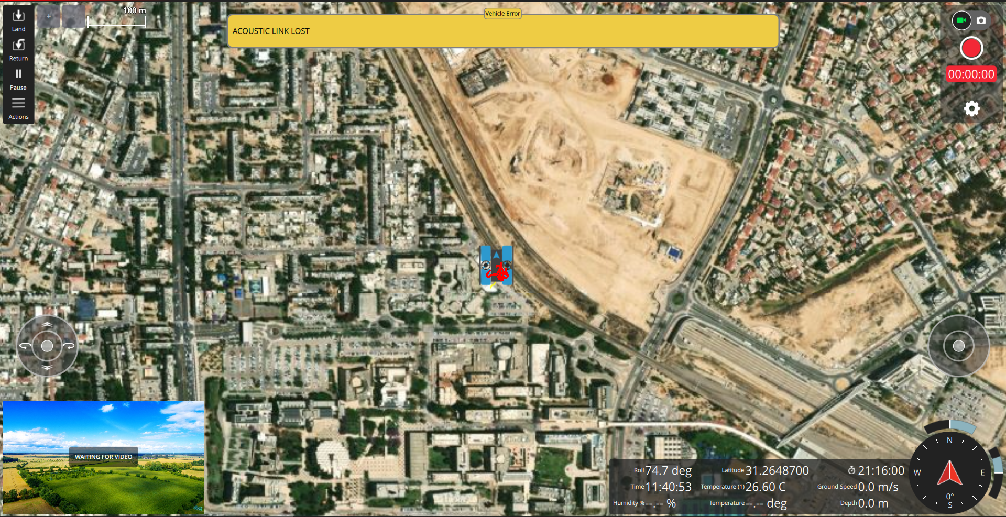
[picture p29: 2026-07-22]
pics/gqc notification sample.png

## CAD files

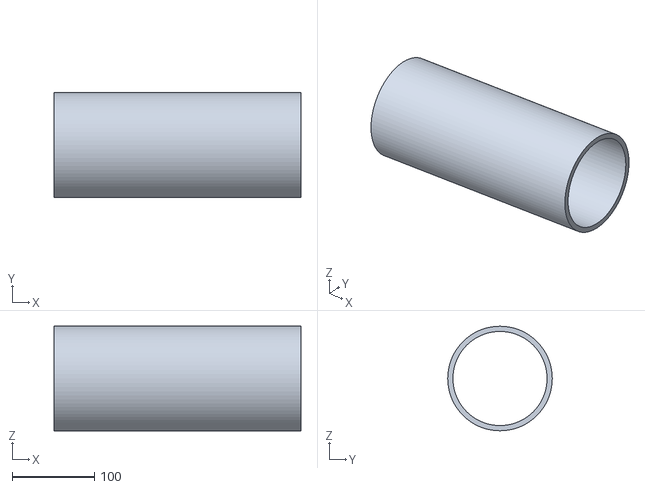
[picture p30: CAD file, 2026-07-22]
src/hauv_description/meshes/main_tube.stl
300.0 x 127.0 x 127.0

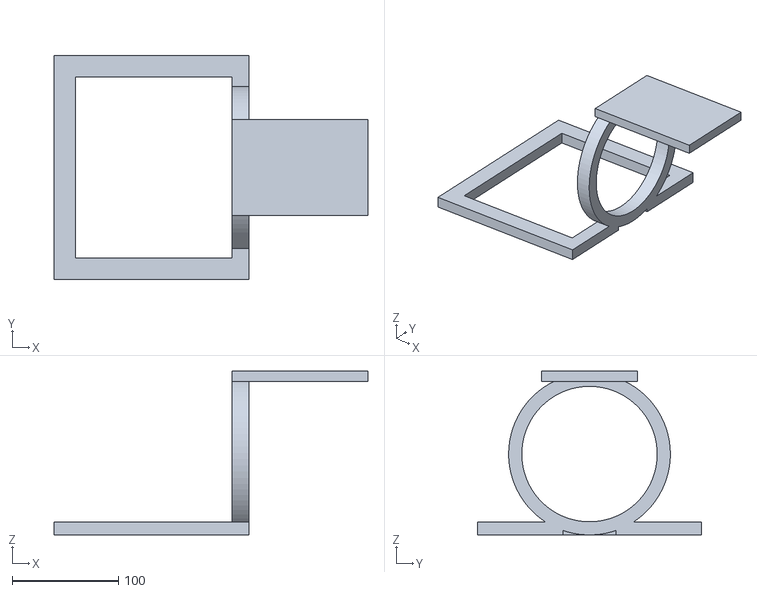
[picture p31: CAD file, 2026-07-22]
src/hauv_description/meshes/mount_aft.stl
295.0 x 210.0 x 154.0

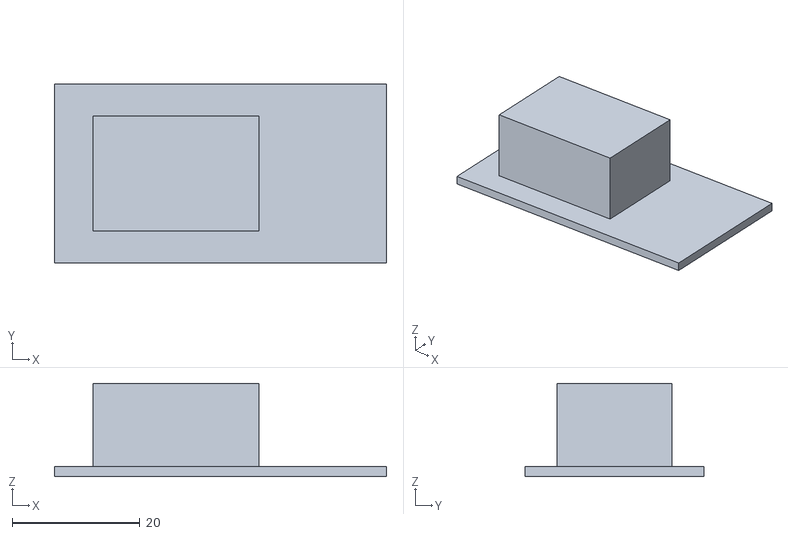
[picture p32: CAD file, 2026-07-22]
src/hauv_description/meshes/esp32.stl
52.0 x 28.0 x 14.6

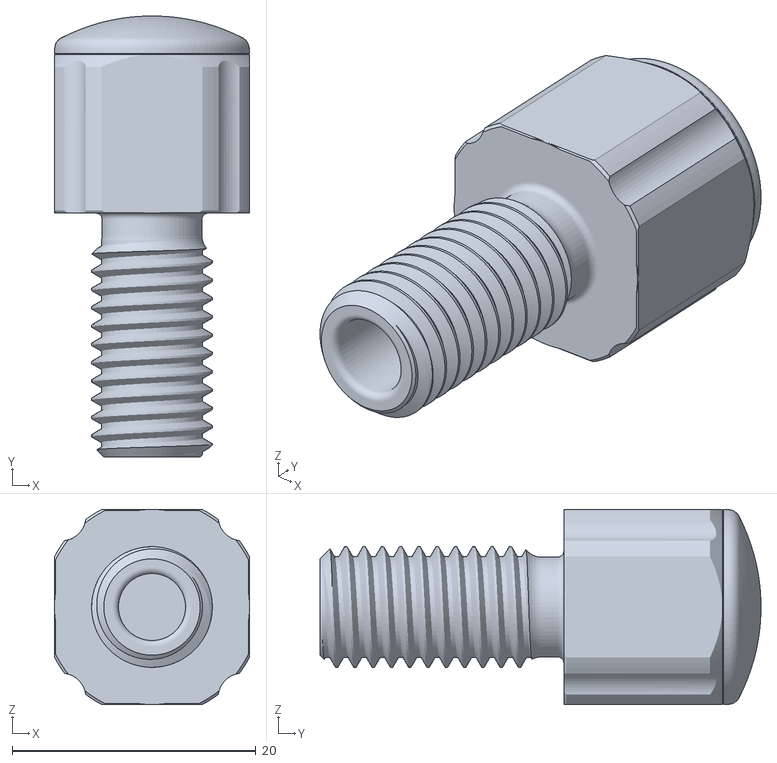
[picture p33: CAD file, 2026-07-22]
src/hauv_description/meshes/indicator.stl
16.0 x 36.2 x 16.0

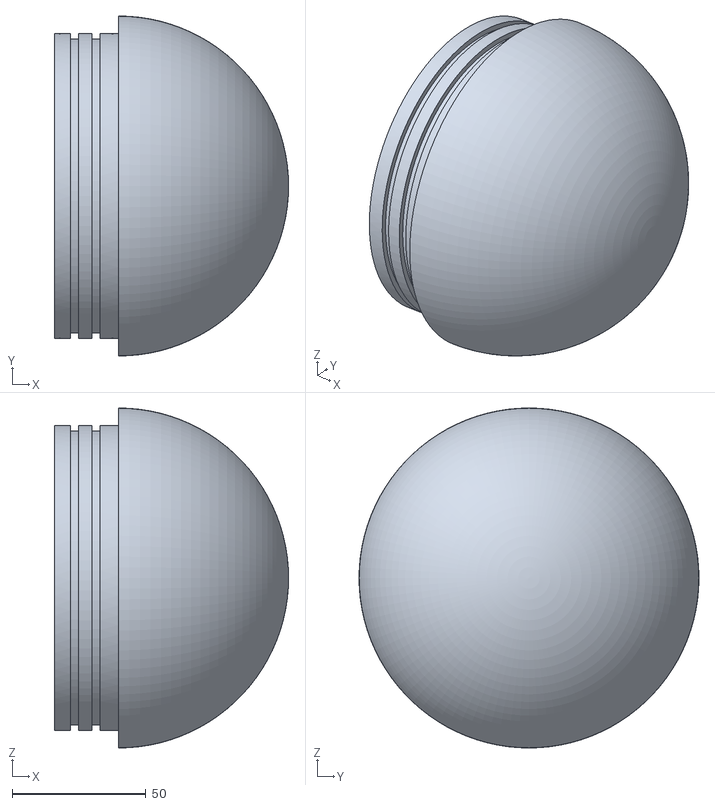
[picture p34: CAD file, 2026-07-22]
src/hauv_description/meshes/dome_fwd.stl
87.5 x 127.0 x 127.0

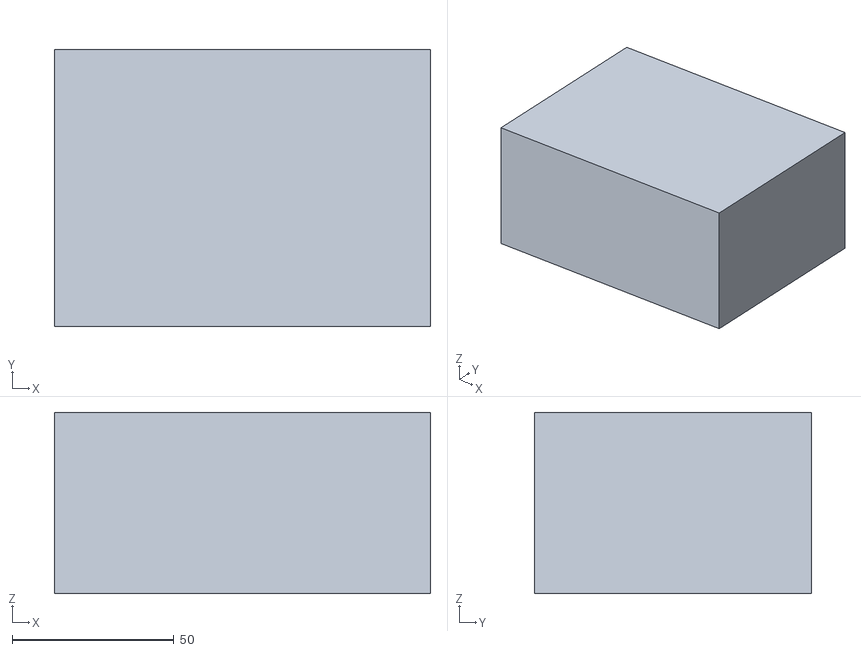
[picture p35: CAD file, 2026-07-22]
src/hauv_description/meshes/dvl_electronics.stl
116.3 x 85.8 x 56.1

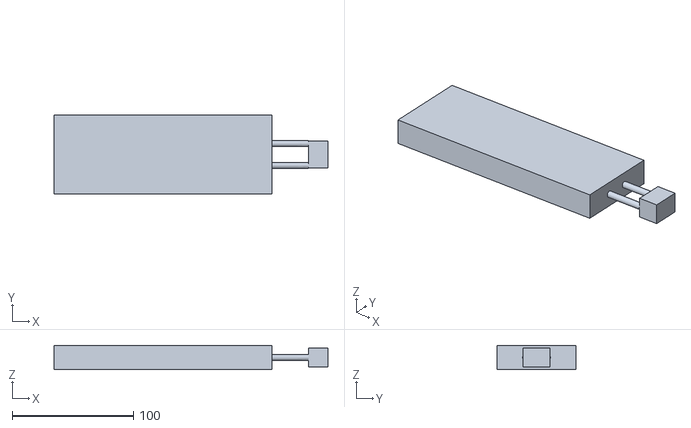
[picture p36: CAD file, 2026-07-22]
src/hauv_description/meshes/battery_large_20Ah.stl
226.0 x 65.0 x 20.0

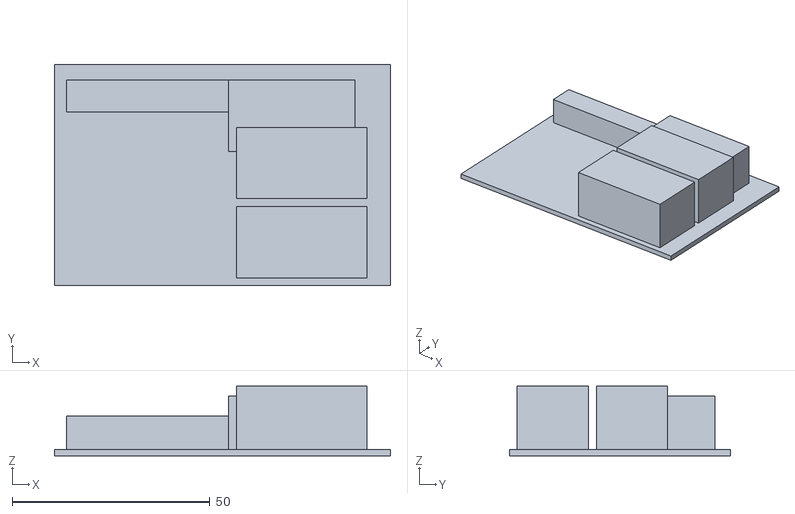
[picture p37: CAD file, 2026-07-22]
src/hauv_description/meshes/upboard.stl
85.0 x 56.0 x 17.6

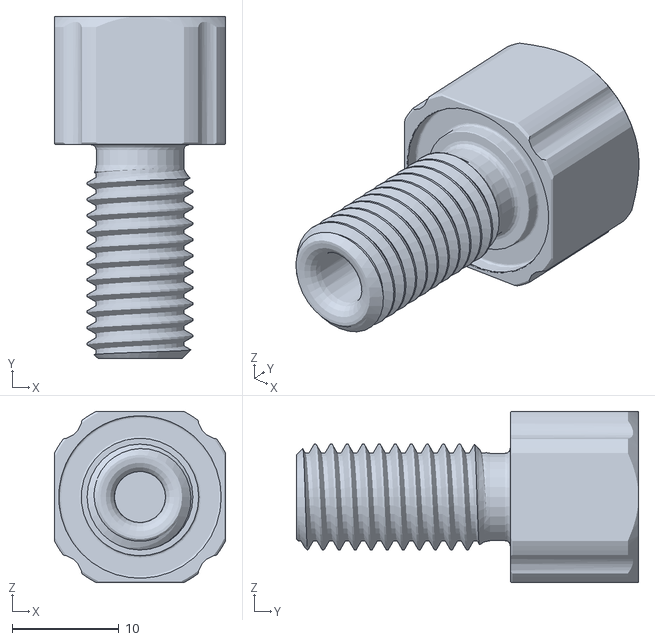
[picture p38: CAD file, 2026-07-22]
src/hauv_description/meshes/bar30.stl
16.0 x 32.0 x 16.0

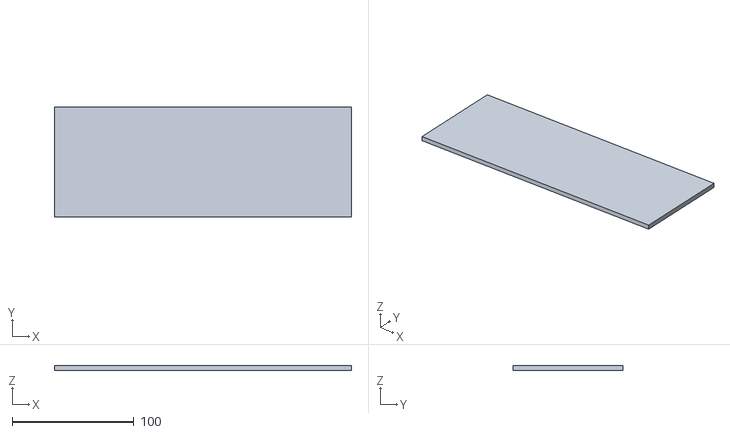
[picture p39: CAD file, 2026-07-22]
src/hauv_description/meshes/tray.stl
244.0 x 90.0 x 4.00

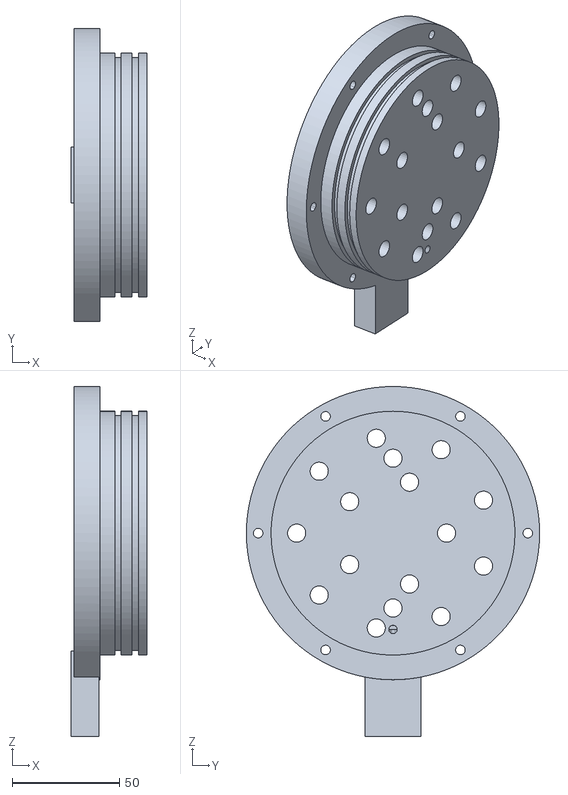
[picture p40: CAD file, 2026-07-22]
src/hauv_description/meshes/cap_aft.stl
35.4 x 137.0 x 163.5

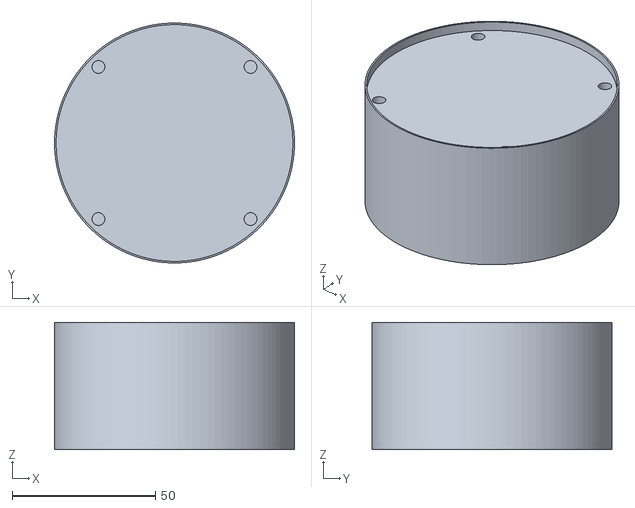
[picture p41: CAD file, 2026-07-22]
src/hauv_description/meshes/dvl_head.stl
83.7 x 83.7 x 44.3

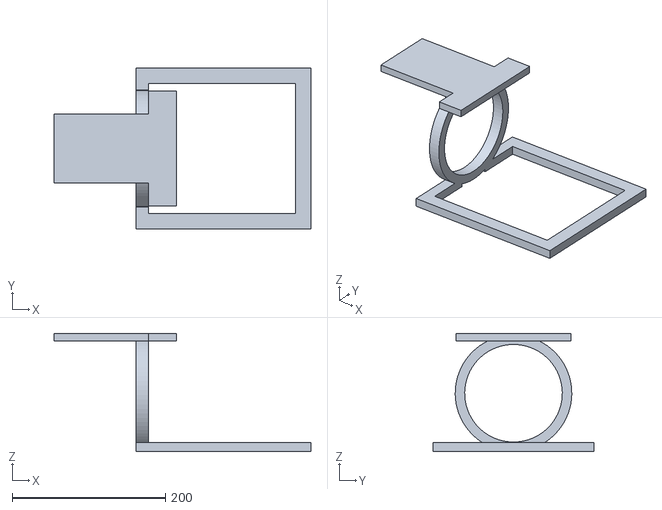
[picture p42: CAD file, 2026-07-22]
src/hauv_description/meshes/mount_fwd.stl
335.0 x 210.0 x 154.0

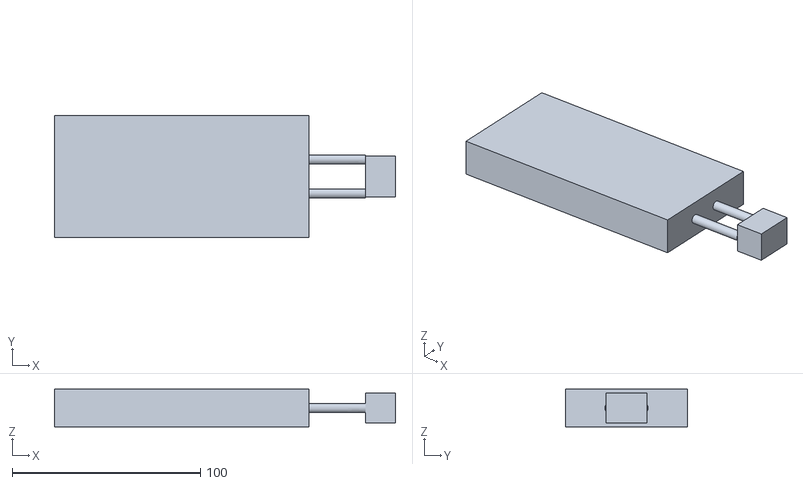
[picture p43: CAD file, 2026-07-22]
src/hauv_description/meshes/battery_small_1p2Ah.stl
181.0 x 65.0 x 20.0

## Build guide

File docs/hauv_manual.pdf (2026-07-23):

HAUV — Operator's Manual | Draft v1.0

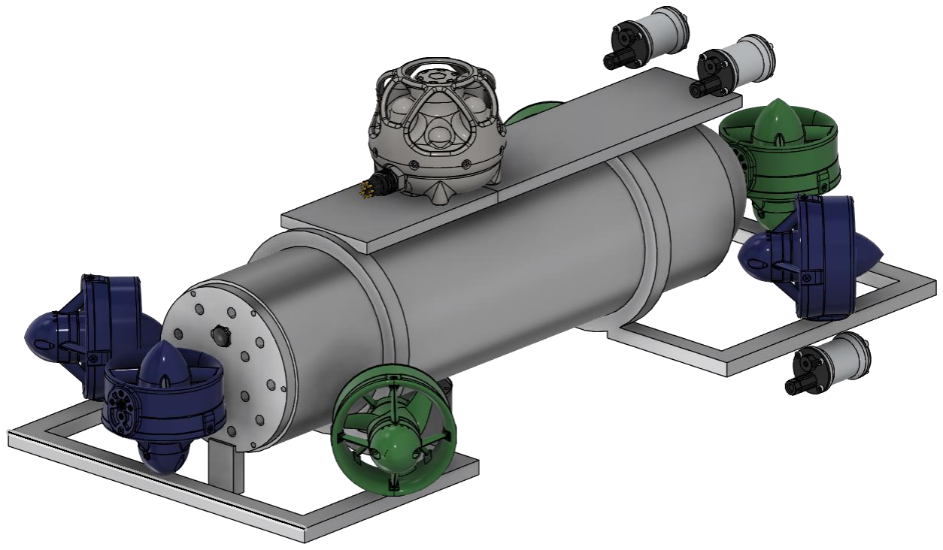
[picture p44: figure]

Proprietary | 1 | Last updated: 19 July 2026

## HAUV Hybrid Autonomous Underwater Vehicle

Operator’s Manual
How to set up, drive and look after the HAUV

Draft v1.0
19 July 2026

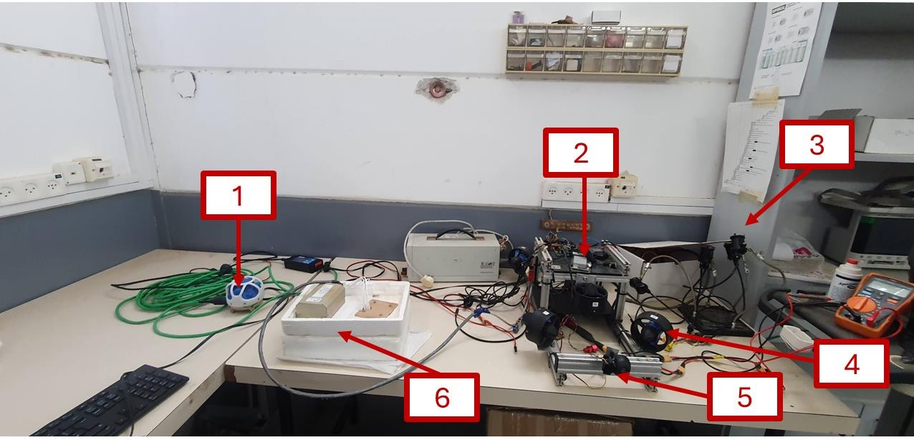
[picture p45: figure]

Proprietary | 2 | Last updated: 19 July 2026

# About the HAUV

### What the HAUV is

The HAUV is a small underwater robot. You drive it from a laptop on the shore or on a boat. It can also drive itself to a point on the map.

### The two computers inside

The HAUV has two computers. They do different jobs. It helps to know which one does what when something goes wrong.

Computer | What it does
UP Board | The “brain”. It thinks. It talks to your laptop, reads the GPS and the DVL, decides where to go, and runs the safety rules.
ESP32 | The “muscles”. It turns the motors, switches the lights, and reads the depth sensor, the compass and the leak sensor.

The two computers talk to each other over a small cable inside the vehicle. If that link breaks, the green indicator light (Figure B, #2) goes off (see Chapter 10).

### The main parts

Figure A shows the vehicle with the main parts numbered.

Figure A — The HAUV and its main parts. The numbers match the table below.

# | Part | What it is for

1 | Subsonus (USBL modem) | Talks to the surface with sound, so the vehicle can be controlled with no cable.

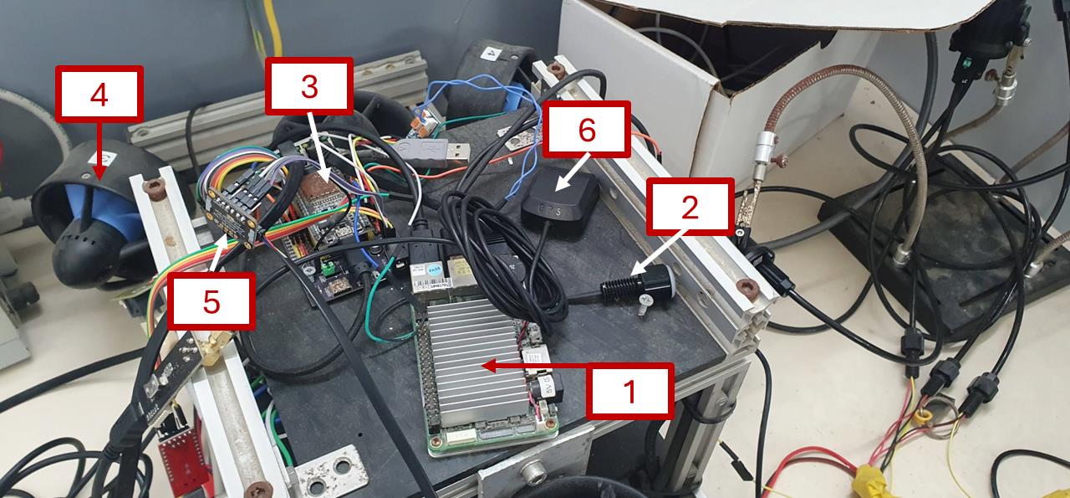
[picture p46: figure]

Proprietary | 3 | Last updated: 19 July 2026
# | Part | What it is for

2 | Electronics tray | Holds the two computers and the boards. See Section 1.4.
3 | Lights | Two sets of lamps. You switch them from the controller.
4 | Thrusters | The propellers that move the vehicle.
5 | Camera | Sends the live picture to your screen.
6 | DVL | Measures speed over the sea floor.

### Inside the vehicle — the electronics

Figure B shows the electronics tray with the main boards numbered. You do not need to touch these to drive the vehicle. It helps to know where they are when something stops working.

Figure B — The electronics tray. The numbers match the table below.

# | Part | What it is for

1 | UP Board | The “brain” — the board with the big metal heatsink.
2 | Indicator lights | 2 lights, red and green next to each other. See Chapter 10.
3 | ESP32 | The “muscles” — the board with the coloured wires.
4 | Thruster | One of the propellers.
5 | I
| 2C connector | Goes to the temperature sensor.
6 | GPS antenna | The small black square marked GPS. Gives the position on the surface.

### What you need before you start

1. The HAUV vehicle, charged.
2. A laptop with QGroundControl installed. We call it QGC.

Proprietary | 4 | Last updated: 19 July 2026
3. An Xbox-style game controller, plugged into the laptop.
4. A network cable (for the cable mode), or the two Subsonus modems (for the sound mode).

# Safety First

Warning! The propellers can cut your fingers. They can start turning at any time when the vehicle is powered on. Keep hands, hair and clothes away.

### The golden rules

1. Never stand next to the propellers when the vehicle is powered on.
2. Always power the vehicle off before you carry it.
3. Do not open the vehicle when it is wet. Dry the outside first.
4. Do not run the thrusters in air for a long time. They need water to stay cool.
5. If you see water inside, stop. Take the vehicle out. Dry it. Find the leak.
6. Do not charge a battery that is hot or damaged.
7. One person drives. One person watches the vehicle and the cable.

### Before every dive

1. Look at the vehicle. Are all screws in place? Is anything broken?
2. Check that all plugs are pushed in fully.
3. Check that the lid is closed and tight.
4. Check the battery is charged.
5. Check the propellers turn freely and nothing is stuck in them.

Note. If anything looks wrong, do not dive. It is always cheaper to fix it on the table than at the bottom of the sea.

# Network Setup

The laptop, the vehicle and the sensors all talk over a network. Each one has its own address. The addresses must be correct or nothing will connect.

### The addresses

Device | Address | Notes
Your laptop (QGC) | 192.168.168.100 | You set this by hand.
UP Board (the brain) | 192.168.168.101 | Fixed. Do not change.

Proprietary | 5 | Last updated: 19 July 2026
Device | Address | Notes
DVL | 192.168.168.102 | Fixed. Do not change.
Subsonus on the surface | 168.254.1.80 | Only for the sound mode.

### Setting your laptop address

1. Open Network settings on your laptop.
2. Find the wired (Ethernet) connection.
3. Choose Manual / Static address.
4. Type address 192.168.168.100 and mask 255.255.255.0.
5. Save.

Tip. To test it, open a terminal and type ping 192.168.168.101. If you get replies, the network is good. If you get nothing, check the cable and the address.

# Connecting QGroundControl

There are two ways to talk to the HAUV:

Way | When to use it
Cable (Ethernet) | Normal work. Fast. You get video and all the numbers.
Sound (Acoustic / USBL) | When the vehicle is under water with no cable. Slow. No video. Only the important numbers.

### Connecting with a cable (Ethernet)

This is the normal way. Do this first when you are learning.

1. Plug the network cable between the laptop and the vehicle.
2. Power the vehicle on.
3. Open QGroundControl on the laptop.
4. Click the Q logo in the top left corner, then Application Settings.
5. Choose Comm Links on the left.
6. Click Add.
7. Fill in the window exactly as shown in Figure C:
- Name: HAUV UP Board
- Type: UDP
- Port: 14550

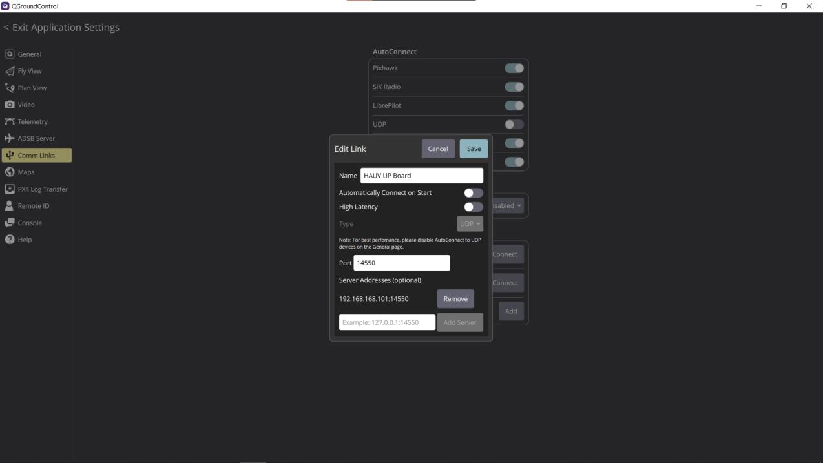
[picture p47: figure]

Proprietary | 6 | Last updated: 19 July 2026
- Server Address: 192.168.168.101:14550, then press Add Server.
8. Click Save.
9. Select HAUV UP Board in the list and click Connect.

Figure C — The QGC “Edit Link” window. Name, port 14550 and the server address 192.168.168.101:14550 must match exactly.

Note. Turn AutoConnect to UDP off on the General page. If you leave it on, QGC may connect to the wrong thing and the vehicle will look dead.

When it works you will see the vehicle appear on the map and the numbers at the bottom of the screen will start moving.

### Connecting with sound (Acoustic / USBL)

Use this when the vehicle is under water and there is no cable. It is slower. You will not get video.

You need two Subsonus modems: one on the surface (in the water, next to you) and one on the vehicle.

1. Put the surface modem in the water. It must be in the water to work.
2. Power both modems on.
3. Open the surface modem page in a web browser. Check the settings match Figure D (address 168.254.1.80).
4. On the vehicle, start the system in sound mode (see Section 5.3).
5. On the laptop, run the bridge program once:
python3 tools/acoustic_qgc_bridge.py
6. In QGC, connect to 127.0.0.1:14551.

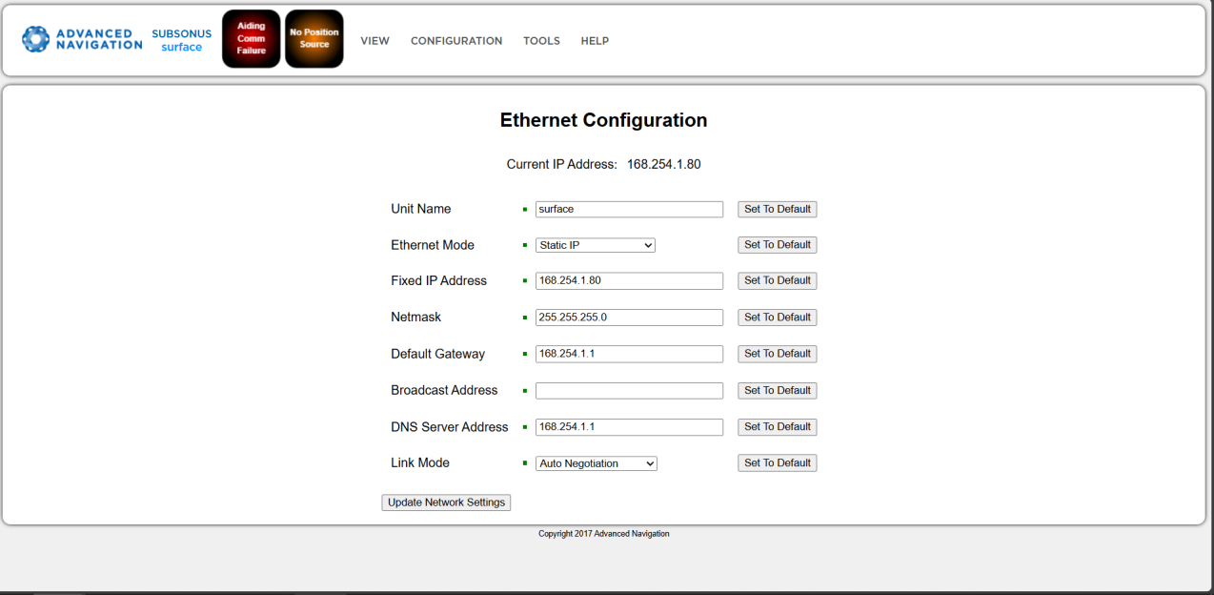
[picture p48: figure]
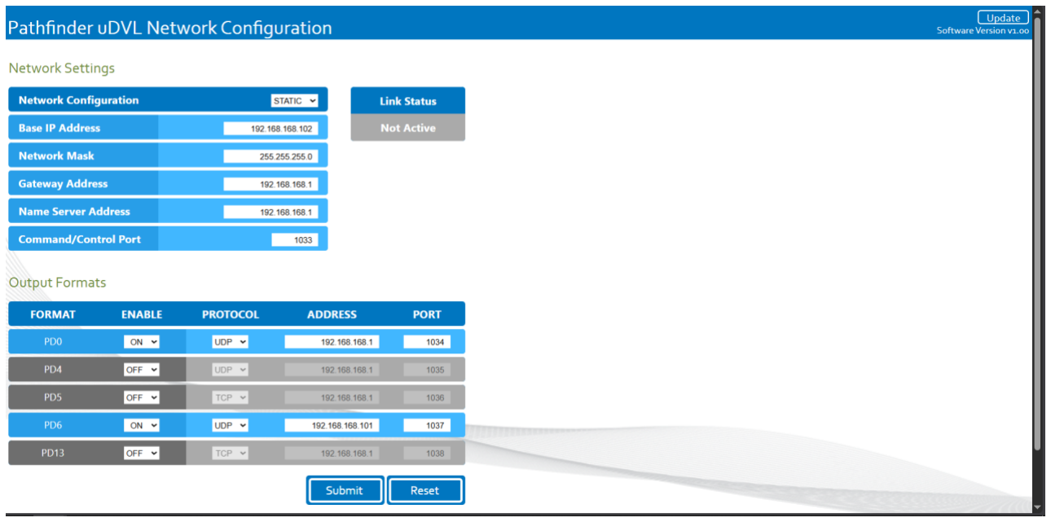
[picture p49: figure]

Proprietary | 7 | Last updated: 19 July 2026

Figure D — The Subsonus surface unit settings page. The address must be 168.254.1.80.

Warning! Run only one copy of the bridge program. If you start it twice, the commands fight each other and the vehicle behaves strangely.

Warning! Both modems must be in the water. Out of the water they cannot hear each other and you will see ACOUSTIC LINK LOST on the screen.

### DVL settings (for reference only)

The DVL is already set up. You do not normally touch it. Figure E shows the correct settings, in case you ever need to check them.

Figure E — DVL network page. Address 192.168.168.102, command port 1033, outputs PD0 and PD6 switched ON.

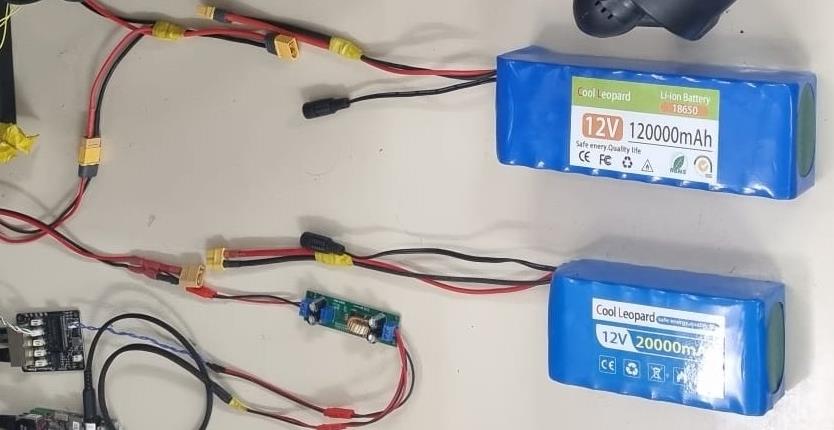
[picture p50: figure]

Proprietary | 8 | Last updated: 19 July 2026

# Starting the HAUV

### The batteries

The HAUV runs on two 12 V lithium battery packs, shown in Figure F. One pack feeds the computers, the other feeds the thrusters. The thick red and black wires join them to the vehicle with yellow plugs.

Figure F — The two 12 V battery packs and how they connect. Red is plus (+), black is minus (–). The small green board is the voltage converter that drops 12 V down for the electronics.

Connecting a battery:

1. Check the vehicle is switched off first.
2. Match the colours: red to red, black to black.
3. Push the yellow plug straight in until it clicks. Do not force it sideways.
4. Check nothing is loose and no bare metal is showing.

Warning! Never join red to black. A short circuit makes a big spark, ruins the battery and can start a fire.

Warning! Do not charge a battery that is hot, swollen or damaged. Do not leave batteries charging without somebody nearby.

Note. Charge both packs after every dive. A pack left flat for a long time can be damaged for good.

### Power on

1. Check Chapter 2 again. Hands away from the propellers.
2. Switch the vehicle on.

Proprietary | 9 | Last updated: 19 July 2026
3. Wait about 30 seconds. The computers need time to wake up.

### Starting the software

All the software is started with one tool called hauv.sh. You run it on the UP Board (the vehicle’s brain), through a terminal.

Command | What it does
./hauv.sh start | Starts everything, cable mode. This is the normal one.
./hauv.sh start --acoustic | Starts everything, sound mode (no cable).
./hauv.sh stop | Stops everything.
./hauv.sh restart | Stops, then starts again.
./hauv.sh check | Tests every sensor and says OK, LOW, FAIL or --.
./hauv.sh status | Shows what is running.
./hauv.sh topics | Lists the live data channels.
./hauv.sh echo DEPTH | Shows live values, for example the depth.
./hauv.sh view mavlink | Opens the log of one program. Press Ctrl+A then D to leave.
./hauv.sh help | Shows help and the short names.

Note. The first time you start the HAUV and connect QGC, it does not open on the main screen. It opens on the Vehicle Configuration screen and shows an error that parameters are missing from the firmware (see Figure G). This happens because QGC thinks the vehicle is running ArduSub. It is not a problem. Click OK, then go back to the main screen (the Fly View).

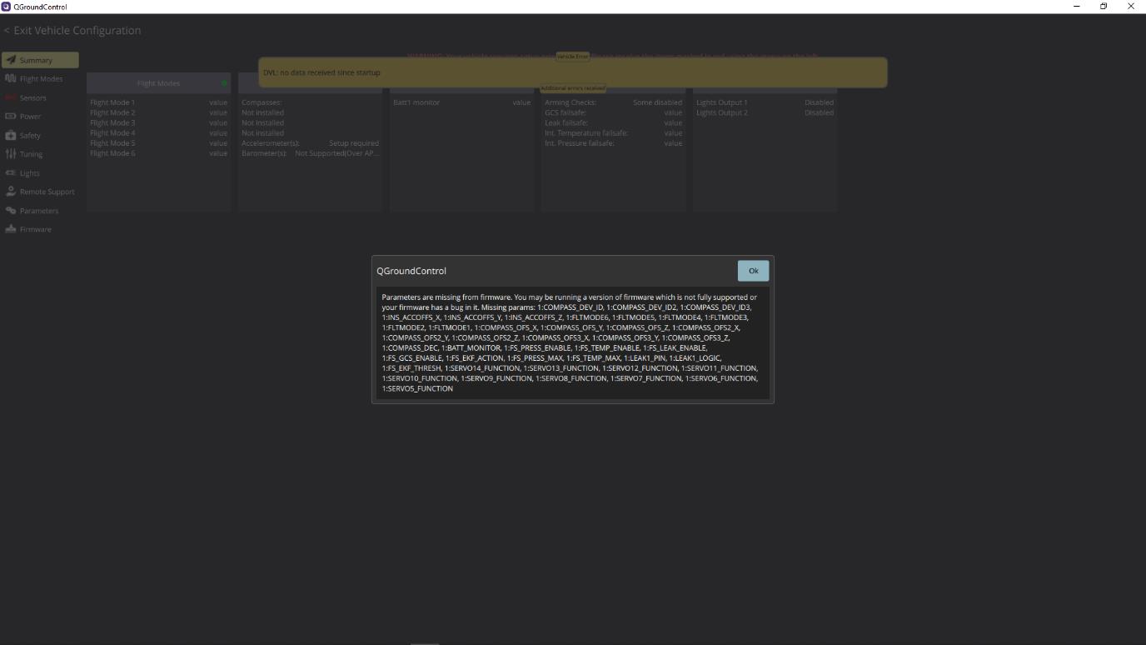
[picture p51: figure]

Proprietary | 10 | Last updated: 19 July 2026

Figure G — The QGC startup screen. On first connection QGC opens here with a firmware-parameter error. This is normal — click OK to go to the main screen.

### Check everything works

Before you put the vehicle in the water, run:

./hauv.sh check

It tests each sensor for a few seconds and prints OK, LOW, FAIL or --.

Result | Meaning
OK | Good. Nothing to do.
LOW | The sensor works but sends data slowly. Usually still fine.
FAIL | No data at all. Fix this before diving.
-- | This sensor only sends data sometimes. Not a problem.

Note. The DVL will say FAIL when the vehicle is out of the water. This is normal. The DVL needs water and a sea floor to see. It will work once you are in the water.

# Reading the Screen

Figure H shows the main QGC screen, called the Fly View. This is what you look at while driving.

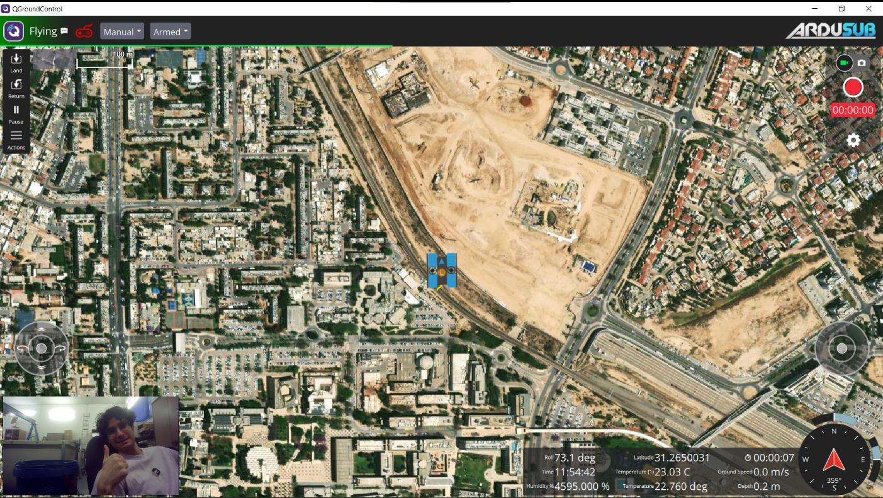
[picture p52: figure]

Proprietary | 11 | Last updated: 19 July 2026

Figure H — The QGC Fly View. The yellow bar at the top is a warning message — here it says ACOUSTIC LINK LOST.

### The parts of the screen

Where | What it shows
Middle | The map. The small vehicle symbol is your HAUV.
Top, yellow or red bar | Warning messages. Read these. See Section 6.3.
Bottom left | The camera picture. Says “WAITING FOR VIDEO” if there is none.
Bottom right | The numbers: depth, roll, temperature, speed, position, time.
Far bottom right | The compass. Shows which way the vehicle points.
Left side | Buttons: Land, Return, Pause, Actions.
Top right | Video record and photo buttons, and the settings gear.

### The numbers you must watch

Number | Why it matters
Depth | How deep you are, in metres. Watch this all the time.
Roll | How much the vehicle is leaning. A big number means it is tipping over.
Ground Speed | How fast you are moving.
Latitude / Longitude | Where you are on the map (surface only).
Temperature | The water temperature.

Proprietary | 12 | Last updated: 19 July 2026

### Warning messages

Messages appear in a coloured bar at the top of the screen. Red and yellow ones are important.

Message | What to do
LEAK! Auto- surfacing | Most serious. Water is inside. The vehicle is already swimming up by itself. Get it out of the water. See Section 9.1.
ACOUSTIC LINK LOST | The sound link stopped. Check both modems are in the water and powered. See Chapter 12.
FAIL: ... | A sensor stopped working. The name after FAIL is the sensor.

Note. The leak message repeats every 3 seconds while the leak is there, so you cannot miss it.

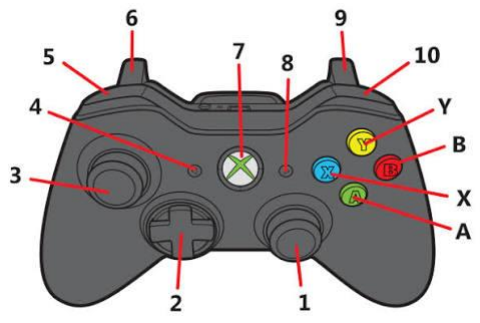
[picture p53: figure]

Proprietary | 13 | Last updated: 19 July 2026

# Driving the HAUV

### The controller

Hold the controller with both hands. The two sticks do the moving. The numbers in Figure I match the table below.

Figure I — The controller. Only the parts listed in the table do anything on the HAUV — the rest are not used.

# | Control | What it does on the HAUV

3 | Left stick | Up / down: move forward and backward. Left / right: slide sideways (crab). The nose keeps pointing the same way.
1 | Right stick | Left / right: turn left and right. Up / down: go up and down in the water.
A | A button | Switch one set of lights on and off.
B | B button | Switch the other set of lights on and off.
5 | LB shoulder | Tilt the camera up.
10 | RB shoulder | Tilt the camera down.

The parts not used for driving are: 2 (D-pad), 4 (Back), 6 and 9 (the two triggers), 7 (Xbox button), 8 (Start), and the X and Y buttons.

Tip. Push the sticks gently. Small movements are enough. The vehicle is heavy and keeps moving after you let go.

### Your first drive

1. Put the vehicle in the water. Hold it until you are ready.
2. Check the screen. The depth should be near 0.

Proprietary | 14 | Last updated: 19 July 2026
3. Push the left stick forward a little. The vehicle should move forward.
4. Pull it back. The vehicle should stop and go back.
5. Turn with the right stick. Watch the compass move.
6. Push the right stick down a little to go deeper. Watch the depth number grow.

Warning! Always know where the vehicle is. If you cannot see it and the screen is frozen, stop and bring it back.

# Flight Modes

The vehicle has three modes. You change them in QGC, at the top of the screen.

### Manual

You control everything with the controller. The vehicle does only what you tell it. Use this most of the time.

### Stabilize

The vehicle tries to stay level by itself. You still drive it. Use this if the vehicle is rolling or tipping too much.

### Guided — “Go to location”

The vehicle drives itself to a point you choose on the map. It keeps its depth on the way, and when it arrives it stays there instead of drifting away.

How to use it:

1. Make sure the vehicle has a GPS position (it must be on the surface).
2. On the map, click the place you want to go.
3. Choose Go to location.
4. The vehicle turns towards the point, then swims to it.
5. When it arrives, it stays there and holds its position and depth.

How to stop it (any of these work):

1. Move any stick on the controller.
2. Change the mode to Manual in QGC.
3. If the link is lost for 5 seconds, the vehicle stops by itself.

Note. While going to the point, the vehicle keeps the depth it had when you pressed Go to location. If you were on the surface, it stays on the surface.

Proprietary | 15 | Last updated: 19 July 2026

# Safety Features

These work by themselves. You do not switch them on.

### Leak — the vehicle swims up by itself

If water gets inside, the leak sensor sees it. Then:

1. The vehicle stops all sideways movement.
2. It drives its up/down thrusters to go up to the surface.
3. It stays on the surface.
4. Your screen shows LEAK! Auto-surfacing in red, again and again.

This ignores everything else. Even if you are driving, or the vehicle is going to a point by itself, the leak wins and the vehicle goes up.

What you must do:

1. Do not fight it. Let it come up.
2. Take the vehicle out of the water.
3. Dry the outside. Then open it and find the water.
4. Do not dive again until you find why water came in.

Note. This works even if the cable or the sound link is broken. The decision is made inside the vehicle, not on your laptop.

Note. When the sensor is dry again for 5 seconds, the vehicle gives control back to you automatically. If the sensor stays wet, it stays on the surface — that is on purpose.

### Lost control link

If the vehicle stops hearing your controller for about 1.5 seconds, it sets all thrusters to stop. It will not keep driving away with the last command.

# Indicator Lights

There is a green light indicator. It tells you if the two computers are talking to each other. You can see where it sits in Figure B — it is number 2.

Green light | Meaning
On, steady | Good. The two computers are talking. Sensors and motors work.
Off | Bad. They are not talking. The motors will not answer. See Chapter 12.

Proprietary | 16 | Last updated: 19 July 2026

Note. Just after you switch the vehicle on, the green light is on for a short time before the connection is really made. Wait about 30 seconds before you trust it.

A red light indicator sits right next to the green one and shows leaks, faults, and when the propellers are live — keep clear of the propellers whenever it is on (see Chapter 2).

Red light | Meaning
Fast Blink | Leak Detected
Solid | Sensor Fault
Slow Blink | Props Live – Keep Clear
Off | All Clear

# After the Dive

1. Bring the vehicle out of the water. Two people if it is heavy.
2. Switch the vehicle off.
3. Wash the outside with fresh water. Salt water eats metal.
4. Pay attention to the propellers. Remove weed, sand and plastic.
5. Dry the vehicle with a cloth.
6. Only when it is dry outside, open it and check for water inside.
7. Charge the battery.

Warning! Never put the vehicle away wet or with a flat battery.

# Troubleshooting

### Common problems

Problem | What to try

QGC does not
connect
1. Check the network cable. 2. Check your laptop address is
| 192.168.168.100. 3. ping 192.168.168.101. 4. Check the link settings match Figure C. 5. Turn AutoConnect UDP off in QGC.
Vehicle shows on screen but nothing moves | The two computers are not talking. Check the green light (Chapter 10). Restart with ./hauv.sh restart.
No video picture | Video only works over the cable. Check the cable mode is running.

Proprietary | 17 | Last updated: 19 July 2026
Problem | What to try
DVL says FAIL | Normal out of the water. If it still fails in the water, check the DVL settings in Figure E.

ACOUSTIC LINK
LOST
1. Both modems must be in the water. 2. Check both are powered.
3. Check only one bridge program is running on the laptop. 4. Check the
| surface modem address (Figure D).
Some sensors say FAIL | Run ./hauv.sh check to see which. Restart with ./hauv.sh restart. If it still fails, the sensor or its plug is bad.
Vehicle drifts away in Go to location | The GPS is only accurate to a few metres. This is normal. Take manual control if you need to be exact.
Vehicle keeps swimming up and will not stop | This is the leak failsafe. There is water inside. See Section 9.1. Get it out of the water.

### Useful checks

Command | Use it to
./hauv.sh check | See which sensors are alive.
./hauv.sh status | See which programs are running.
./hauv.sh echo DEPTH | Watch the depth value live.
./hauv.sh echo LEAK | Check the leak sensor (0 = dry, 1 = water).
./hauv.sh view guidance | Read the messages from the driving program.
./hauv.sh restart | The general “switch it off and on again”.

Tip. If you are lost, ./hauv.sh restart fixes most software problems. It does not fix broken cables or wet electronics.

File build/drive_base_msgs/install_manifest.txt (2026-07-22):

/home/up/rov_ws/install/drive_base_msgs/share/ament_index/resource_index/rosidl_interfaces/drive_base_msgs
/home/up/rov_ws/install/drive_base_msgs/include/drive_base_msgs/msg/command_status.h
/home/up/rov_ws/install/drive_base_msgs/include/drive_base_msgs/msg/rosidl_generator_c__visibility_control.h
/home/up/rov_ws/install/drive_base_msgs/include/drive_base_msgs/msg/detail/base_info__struct.h
/home/up/rov_ws/install/drive_base_msgs/include/drive_base_msgs/msg/detail/command_header__type_support.h
/home/up/rov_ws/install/drive_base_msgs/include/drive_base_msgs/msg/detail/command_status__functions.h
/home/up/rov_ws/install/drive_base_msgs/include/drive_base_msgs/msg/detail/base_info__functions.h
/home/up/rov_ws/install/drive_base_msgs/include/drive_base_msgs/msg/detail/command_status__struct.h
/home/up/rov_ws/install/drive_base_msgs/include/drive_base_msgs/msg/detail/command_header__functions.c
/home/up/rov_ws/install/drive_base_msgs/include/drive_base_msgs/msg/detail/base_info__type_support.h
/home/up/rov_ws/install/drive_base_msgs/include/drive_base_msgs/msg/detail/trv_command__type_support.h
/home/up/rov_ws/install/drive_base_msgs/include/drive_base_msgs/msg/detail/command_header__functions.h
/home/up/rov_ws/install/drive_base_msgs/include/drive_base_msgs/msg/detail/trv_command__functions.c
/home/up/rov_ws/install/drive_base_msgs/include/drive_base_msgs/msg/detail/base_info__functions.c
/home/up/rov_ws/install/drive_base_msgs/include/drive_base_msgs/msg/detail/command_status__type_support.h
/home/up/rov_ws/install/drive_base_msgs/include/drive_base_msgs/msg/detail/command_status__functions.c
/home/up/rov_ws/install/drive_base_msgs/include/drive_base_msgs/msg/detail/trv_command__struct.h
/home/up/rov_ws/install/drive_base_msgs/include/drive_base_msgs/msg/detail/trv_command__functions.h
/home/up/rov_ws/install/drive_base_msgs/include/drive_base_msgs/msg/detail/command_header__struct.h
/home/up/rov_ws/install/drive_base_msgs/include/drive_base_msgs/msg/command_header.h
/home/up/rov_ws/install/drive_base_msgs/include/drive_base_msgs/msg/base_info.h
/home/up/rov_ws/install/drive_base_msgs/include/drive_base_msgs/msg/trv_command.h
/home/up/rov_ws/install/drive_base_msgs/share/drive_base_msgs/environment/library_path.sh
/home/up/rov_ws/install/drive_base_msgs/share/drive_base_msgs/environment/library_path.dsv
/home/up/rov_ws/install/drive_base_msgs/lib/libdrive_base_msgs__rosidl_generator_c.so
/home/up/rov_ws/install/drive_base_msgs/include/drive_base_msgs/msg/detail/trv_command__rosidl_typesupport_fastrtps_c.h
/home/up/rov_ws/install/drive_base_msgs/include/drive_base_msgs/msg/detail/base_info__rosidl_typesupport_fastrtps_c.h
/home/up/rov_ws/install/drive_base_msgs/include/drive_base_msgs/msg/detail/command_header__rosidl_typesupport_fastrtps_c.h
/home/up/rov_ws/install/drive_base_msgs/include/drive_base_msgs/msg/detail/command_status__rosidl_typesupport_fastrtps_c.h
/home/up/rov_ws/install/drive_base_msgs/include/drive_base_msgs/msg/rosidl_typesupport_fastrtps_c__visibility_control.h
/home/up/rov_ws/install/drive_base_msgs/lib/libdrive_base_msgs__rosidl_typesupport_fastrtps_c.so
/home/up/rov_ws/install/drive_base_msgs/include/drive_base_msgs/msg/rosidl_typesupport_fastrtps_cpp__visibility_control.h
/home/up/rov_ws/install/drive_base_msgs/include/drive_base_msgs/msg/detail/command_status__rosidl_typesupport_fastrtps_cpp.hpp
/home/up/rov_ws/install/drive_base_msgs/include/drive_base_msgs/msg/detail/base_info__rosidl_typesupport_fastrtps_cpp.hpp
/home/up/rov_ws/install/drive_base_msgs/include/drive_base_msgs/msg/detail/trv_command__rosidl_typesupport_fastrtps_cpp.hpp
/home/up/rov_ws/install/drive_base_msgs/include/drive_base_msgs/msg/detail/command_header__rosidl_typesupport_fastrtps_cpp.hpp
/home/up/rov_ws/install/drive_base_msgs/lib/libdrive_base_msgs__rosidl_typesupport_fastrtps_cpp.so
/home/up/rov_ws/install/drive_base_msgs/include/drive_base_msgs/msg/detail/base_info__rosidl_typesupport_introspection_c.h
/home/up/rov_ws/install/drive_base_msgs/include/drive_base_msgs/msg/detail/command_status__rosidl_typesupport_introspection_c.h
/home/up/rov_ws/install/drive_base_msgs/include/drive_base_msgs/msg/detail/command_status__type_support.c
/home/up/rov_ws/install/drive_base_msgs/include/drive_base_msgs/msg/detail/base_info__type_support.c
/home/up/rov_ws/install/drive_base_msgs/include/drive_base_msgs/msg/detail/command_header__rosidl_typesupport_introspection_c.h
/home/up/rov_ws/install/drive_base_msgs/include/drive_base_msgs/msg/detail/trv_command__type_support.c
/home/up/rov_ws/install/drive_base_msgs/include/drive_base_msgs/msg/detail/trv_command__rosidl_typesupport_introspection_c.h
/home/up/rov_ws/install/drive_base_msgs/include/drive_base_msgs/msg/detail/command_header__type_support.c
/home/up/rov_ws/install/drive_base_msgs/include/drive_base_msgs/msg/rosidl_typesupport_introspection_c__visibility_control.h
/home/up/rov_ws/install/drive_base_msgs/lib/libdrive_base_msgs__rosidl_typesupport_introspection_c.so
/home/up/rov_ws/install/drive_base_msgs/lib/libdrive_base_msgs__rosidl_typesupport_c.so
/home/up/rov_ws/install/drive_base_msgs/include/drive_base_msgs/msg/base_info.hpp
/home/up/rov_ws/install/drive_base_msgs/include/drive_base_msgs/msg/command_header.hpp
/home/up/rov_ws/install/drive_base_msgs/include/drive_base_msgs/msg/detail/base_info__struct.hpp
/home/up/rov_ws/install/drive_base_msgs/include/drive_base_msgs/msg/detail/command_status__builder.hpp
/home/up/rov_ws/install/drive_base_msgs/include/drive_base_msgs/msg/detail/base_info__traits.hpp
/home/up/rov_ws/install/drive_base_msgs/include/drive_base_msgs/msg/detail/command_header__builder.hpp
/home/up/rov_ws/install/drive_base_msgs/include/drive_base_msgs/msg/detail/trv_command__builder.hpp
/home/up/rov_ws/install/drive_base_msgs/include/drive_base_msgs/msg/detail/command_status__struct.hpp
/home/up/rov_ws/install/drive_base_msgs/include/drive_base_msgs/msg/detail/command_status__type_support.hpp
/home/up/rov_ws/install/drive_base_msgs/include/drive_base_msgs/msg/detail/command_status__traits.hpp
/home/up/rov_ws/install/drive_base_msgs/include/drive_base_msgs/msg/detail/command_header__struct.hpp
/home/up/rov_ws/install/drive_base_msgs/include/drive_base_msgs/msg/detail/command_header__type_support.hpp
/home/up/rov_ws/install/drive_base_msgs/include/drive_base_msgs/msg/detail/trv_command__type_support.hpp
/home/up/rov_ws/install/drive_base_msgs/include/drive_base_msgs/msg/detail/command_header__traits.hpp
/home/up/rov_ws/install/drive_base_msgs/include/drive_base_msgs/msg/detail/trv_command__traits.hpp
/home/up/rov_ws/install/drive_base_msgs/include/drive_base_msgs/msg/detail/base_info__type_support.hpp
/home/up/rov_ws/install/drive_base_msgs/include/drive_base_msgs/msg/detail/trv_command__struct.hpp
/home/up/rov_ws/install/drive_base_msgs/include/drive_base_msgs/msg/detail/base_info__builder.hpp
/home/up/rov_ws/install/drive_base_msgs/include/drive_base_msgs/msg/command_status.hpp
/home/up/rov_ws/install/drive_base_msgs/include/drive_base_msgs/msg/trv_command.hpp
/home/up/rov_ws/install/drive_base_msgs/include/drive_base_msgs/msg/rosidl_generator_cpp__visibility_control.hpp
/home/up/rov_ws/install/drive_base_msgs/include/drive_base_msgs/msg/detail/base_info__type_support.cpp
/home/up/rov_ws/install/drive_base_msgs/include/drive_base_msgs/msg/detail/command_header__rosidl_typesupport_introspection_cpp.hpp
/home/up/rov_ws/install/drive_base_msgs/include/drive_base_msgs/msg/detail/command_status__rosidl_typesupport_introspection_cpp.hpp
/home/up/rov_ws/install/drive_base_msgs/include/drive_base_msgs/msg/detail/trv_command__rosidl_typesupport_introspection_cpp.hpp
/home/up/rov_ws/install/drive_base_msgs/include/drive_base_msgs/msg/detail/trv_command__type_support.cpp
/home/up/rov_ws/install/drive_base_msgs/include/drive_base_msgs/msg/detail/command_header__type_support.cpp
/home/up/rov_ws/install/drive_base_msgs/include/drive_base_msgs/msg/detail/base_info__rosidl_typesupport_introspection_cpp.hpp
/home/up/rov_ws/install/drive_base_msgs/include/drive_base_msgs/msg/detail/command_status__type_support.cpp
/home/up/rov_ws/install/drive_base_msgs/lib/libdrive_base_msgs__rosidl_typesupport_introspection_cpp.so
/home/up/rov_ws/install/drive_base_msgs/lib/libdrive_base_msgs__rosidl_typesupport_cpp.so
/home/up/rov_ws/install/drive_base_msgs/share/drive_base_msgs/environment/pythonpath.sh
/home/up/rov_ws/install/drive_base_msgs/share/drive_base_msgs/environment/pythonpath.dsv
/home/up/rov_ws/install/drive_base_msgs/lib/python3.8/site-packages/drive_base_msgs/__init__.py
/home/up/rov_ws/install/drive_base_msgs/lib/python3.8/site-packages/drive_base_msgs/msg/_trv_command.py
/home/up/rov_ws/install/drive_base_msgs/lib/python3.8/site-packages/drive_base_msgs/msg/__init__.py
/home/up/rov_ws/install/drive_base_msgs/lib/python3.8/site-packages/drive_base_msgs/msg/_command_status_s.c
/home/up/rov_ws/install/drive_base_msgs/lib/python3.8/site-packages/drive_base_msgs/msg/_command_header.py
/home/up/rov_ws/install/drive_base_msgs/lib/python3.8/site-packages/drive_base_msgs/msg/_base_info_s.c
/home/up/rov_ws/install/drive_base_msgs/lib/python3.8/site-packages/drive_base_msgs/msg/_command_header_s.c
/home/up/rov_ws/install/drive_base_msgs/lib/python3.8/site-packages/drive_base_msgs/msg/_base_info.py
/home/up/rov_ws/install/drive_base_msgs/lib/python3.8/site-packages/drive_base_msgs/msg/_command_status.py
/home/up/rov_ws/install/drive_base_msgs/lib/python3.8/site-packages/drive_base_msgs/msg/_trv_command_s.c
/home/up/rov_ws/install/drive_base_msgs/lib/python3.8/site-packages/drive_base_msgs/drive_base_msgs_s__rosidl_typesupport_fastrtps_c.cpython-38-x86_64-linux-gnu.so
/home/up/rov_ws/install/drive_base_msgs/lib/python3.8/site-packages/drive_base_msgs/drive_base_msgs_s__rosidl_typesupport_introspection_c.cpython-38-x86_64-linux-gnu.so
/home/up/rov_ws/install/drive_base_msgs/lib/python3.8/site-packages/drive_base_msgs/drive_base_msgs_s__rosidl_typesupport_c.cpython-38-x86_64-linux-gnu.so
/home/up/rov_ws/install/drive_base_msgs/lib/libdrive_base_msgs__python.so
/home/up/rov_ws/install/drive_base_msgs/share/drive_base_msgs/msg/CommandHeader.idl
/home/up/rov_ws/install/drive_base_msgs/share/drive_base_msgs/msg/BaseInfo.idl
/home/up/rov_ws/install/drive_base_msgs/share/drive_base_msgs/msg/CommandStatus.idl
/home/up/rov_ws/install/drive_base_msgs/share/drive_base_msgs/msg/TRVCommand.idl
/home/up/rov_ws/install/drive_base_msgs/share/drive_base_msgs/msg/CommandHeader.msg
/home/up/rov_ws/install/drive_base_msgs/share/drive_base_msgs/msg/BaseInfo.msg
/home/up/rov_ws/install/drive_base_msgs/share/drive_base_msgs/msg/CommandStatus.msg
/home/up/rov_ws/install/drive_base_msgs/share/drive_base_msgs/msg/TRVCommand.msg
/home/up/rov_ws/install/drive_base_msgs/share/ament_index/resource_index/package_run_dependencies/drive_base_msgs
/home/up/rov_ws/install/drive_base_msgs/share/ament_index/resource_index/parent_prefix_path/drive_base_msgs
/home/up/rov_ws/install/drive_base_msgs/share/drive_base_msgs/environment/ament_prefix_path.sh
/home/up/rov_ws/install/drive_base_msgs/share/drive_base_msgs/environment/ament_prefix_path.dsv
/home/up/rov_ws/install/drive_base_msgs/share/drive_base_msgs/environment/path.sh
/home/up/rov_ws/install/drive_base_msgs/share/drive_base_msgs/environment/path.dsv
/home/up/rov_ws/install/drive_base_msgs/share/drive_base_msgs/local_setup.bash
/home/up/rov_ws/install/drive_base_msgs/share/drive_base_msgs/local_setup.sh
/home/up/rov_ws/install/drive_base_msgs/share/drive_base_msgs/local_setup.zsh
/home/up/rov_ws/install/drive_base_msgs/share/drive_base_msgs/local_setup.dsv
/home/up/rov_ws/install/drive_base_msgs/share/drive_base_msgs/package.dsv
/home/up/rov_ws/install/drive_base_msgs/share/ament_index/resource_index/packages/drive_base_msgs
/home/up/rov_ws/install/drive_base_msgs/share/drive_base_msgs/cmake/drive_base_msgs__rosidl_generator_cExport.cmake
/home/up/rov_ws/install/drive_base_msgs/share/drive_base_msgs/cmake/drive_base_msgs__rosidl_generator_cExport-noconfig.cmake
/home/up/rov_ws/install/drive_base_msgs/share/drive_base_msgs/cmake/drive_base_msgs__rosidl_typesupport_introspection_cExport.cmake
/home/up/rov_ws/install/drive_base_msgs/share/drive_base_msgs/cmake/drive_base_msgs__rosidl_typesupport_introspection_cExport-noconfig.cmake
/home/up/rov_ws/install/drive_base_msgs/share/drive_base_msgs/cmake/drive_base_msgs__rosidl_typesupport_cExport.cmake
/home/up/rov_ws/install/drive_base_msgs/share/drive_base_msgs/cmake/drive_base_msgs__rosidl_typesupport_cExport-noconfig.cmake
/home/up/rov_ws/install/drive_base_msgs/share/drive_base_msgs/cmake/drive_base_msgs__rosidl_generator_cppExport.cmake
/home/up/rov_ws/install/drive_base_msgs/share/drive_base_msgs/cmake/drive_base_msgs__rosidl_typesupport_introspection_cppExport.cmake
/home/up/rov_ws/install/drive_base_msgs/share/drive_base_msgs/cmake/drive_base_msgs__rosidl_typesupport_introspection_cppExport-noconfig.cmake
/home/up/rov_ws/install/drive_base_msgs/share/drive_base_msgs/cmake/drive_base_msgs__rosidl_typesupport_cppExport.cmake
/home/up/rov_ws/install/drive_base_msgs/share/drive_base_msgs/cmake/drive_base_msgs__rosidl_typesupport_cppExport-noconfig.cmake
/home/up/rov_ws/install/drive_base_msgs/share/drive_base_msgs/cmake/rosidl_cmake-extras.cmake
/home/up/rov_ws/install/drive_base_msgs/share/drive_base_msgs/cmake/ament_cmake_export_dependencies-extras.cmake
/home/up/rov_ws/install/drive_base_msgs/share/drive_base_msgs/cmake/ament_cmake_export_libraries-extras.cmake
/home/up/rov_ws/install/drive_base_msgs/share/drive_base_msgs/cmake/ament_cmake_export_targets-extras.cmake
/home/up/rov_ws/install/drive_base_msgs/share/drive_base_msgs/cmake/ament_cmake_export_include_directories-extras.cmake
/home/up/rov_ws/install/drive_base_msgs/share/drive_base_msgs/cmake/rosidl_cmake_export_typesupport_libraries-extras.cmake
/home/up/rov_ws/install/drive_base_msgs/share/drive_base_msgs/cmake/rosidl_cmake_export_typesupport_targets-extras.cmake
/home/up/rov_ws/install/drive_base_msgs/share/drive_base_msgs/cmake/drive_base_msgsConfig.cmake
/home/up/rov_ws/install/drive_base_msgs/share/drive_base_msgs/cmake/drive_base_msgsConfig-version.cmake
/home/up/rov_ws/install/drive_base_msgs/share/drive_base_msgs/package.xml

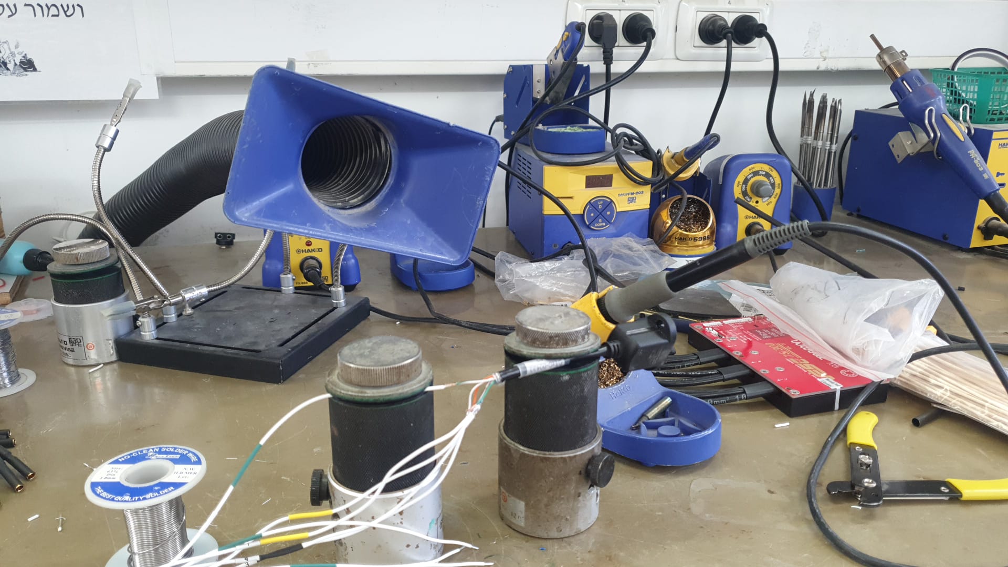
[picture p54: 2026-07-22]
pics/soldering subsonus cable.jpg

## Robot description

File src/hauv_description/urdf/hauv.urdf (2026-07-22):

<?xml version="1.0"?>
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
<robot name="hauv">

  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
  <link name="base_link">
    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

    <inertial>
      <origin xyz="-0.02 0 -0.01" rpy="0 0 0"/>
      <mass value="5.531"/>
      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
    </inertial>
  </link>

  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

  <link name="t1_front_left">
    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
  </link>
  <joint name="t1_front_left_joint" type="continuous">
    <parent link="base_link"/><child link="t1_front_left"/>
    <origin xyz="0.24760 0.09260 -0.01400" rpy="0 0 0.785398"/>
    <axis xyz="1 0 0"/>
  </joint>

  <link name="t2_front_right">
    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
  </link>
  <joint name="t2_front_right_joint" type="continuous">
    <parent link="base_link"/><child link="t2_front_right"/>
    <origin xyz="0.24760 -0.09260 -0.01400" rpy="0 0 -0.785398"/>
    <axis xyz="1 0 0"/>
  </joint>

  <link name="t3_rear_left">
    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
  </link>
  <joint name="t3_rear_left_joint" type="continuous">
    <parent link="base_link"/><child link="t3_rear_left"/>
    <origin xyz="-0.25240 0.09740 -0.01400" rpy="0 0 -0.785398"/>
    <axis xyz="1 0 0"/>
  </joint>

  <link name="t4_rear_right">
    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
  </link>
  <joint name="t4_rear_right_joint" type="continuous">
    <parent link="base_link"/><child link="t4_rear_right"/>
    <origin xyz="-0.25240 -0.09740 -0.01400" rpy="0 0 0.785398"/>
    <axis xyz="1 0 0"/>
  </joint>

  <link name="t5_vert_front">
    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
  </link>
  <joint name="t5_vert_front_joint" type="continuous">
    <parent link="base_link"/><child link="t5_vert_front"/>
    <origin xyz="0.30360 0 0.00440" rpy="0 -1.570796 -3.141593"/>
    <axis xyz="1 0 0"/>
  </joint>

  <link name="t6_vert_rear">
    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
  </link>
  <joint name="t6_vert_rear_joint" type="continuous">
    <parent link="base_link"/><child link="t6_vert_rear"/>
    <origin xyz="-0.30640 0 0.00440" rpy="0 -1.570796 -3.141593"/>
    <axis xyz="1 0 0"/>
  </joint>

  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

  <link name="light_lower_left">
    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
  </link>
  <joint name="light_lower_left_joint" type="fixed">
    <parent link="base_link"/><child link="light_lower_left"/>
    <origin xyz="0.13630 0.11500 -0.49450" rpy="1.570796 0 -1.570796"/>
  </joint>

  <link name="light_lower_right">
    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
  </link>
  <joint name="light_lower_right_joint" type="fixed">
    <parent link="base_link"/><child link="light_lower_right"/>
    <origin xyz="0.13630 -0.07500 -0.49450" rpy="1.570796 0 -1.570796"/>
  </joint>

  <link name="light_upper_left">
    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
  </link>
  <joint name="light_upper_left_joint" type="fixed">
    <parent link="base_link"/><child link="light_upper_left"/>
    <origin xyz="0.13630 0.06500 -0.28580" rpy="1.570796 0 -1.570796"/>
  </joint>

  <link name="light_upper_right">
    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
  </link>
  <joint name="light_upper_right_joint" type="fixed">
    <parent link="base_link"/><child link="light_upper_right"/>
    <origin xyz="0.13630 -0.02500 -0.28580" rpy="1.570796 0 -1.570796"/>
  </joint>

  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

  <link name="subsonus">
    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
  </link>
  <joint name="subsonus_joint" type="fixed">
    <parent link="base_link"/><child link="subsonus"/>
    <origin xyz="-0.04000 0 0.07860" rpy="1.570796 0 1.570796"/>
  </joint>

  <link name="bar30">
    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
  </link>
  <joint name="bar30_joint" type="fixed">
    <parent link="base_link"/><child link="bar30"/>
    <origin xyz="-0.17850 0 -0.09500" rpy="-1.570796 0 0"/>
  </joint>

  <link name="indicator">
    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
  </link>
  <joint name="indicator_joint" type="fixed">
    <parent link="base_link"/><child link="indicator"/>
    <origin xyz="-0.19000 0 0.02500" rpy="0 0 1.570796"/>
  </joint>

  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

  <link name="camera_link"/>
  <joint name="camera_joint" type="fixed">
    <parent link="base_link"/><child link="camera_link"/>
    <origin xyz="0.1274 0 0" rpy="0 0 0"/>
  </joint>

  <link name="dvl_link"/>
  <joint name="dvl_joint" type="fixed">
    <parent link="base_link"/><child link="dvl_link"/>
    <origin xyz="-0.0850 0 -0.1083" rpy="0 0 0"/>
  </joint>

</robot>

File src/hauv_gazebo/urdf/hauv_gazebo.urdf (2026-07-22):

<?xml version="1.0"?>
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
<robot name="hauv">

  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

  <link name="base_link">
    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
    <inertial>
      <origin xyz="-0.0221 0.0 0.0120" rpy="0 0 0"/>
      <mass value="9.972"/>
      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
    </inertial>
  </link>

  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

  <link name="t1_front_left">
    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
    <inertial><mass value="0.344"/>
      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</inertial>
  </link>
  <joint name="t1_front_left_joint" type="continuous">
    <parent link="base_link"/><child link="t1_front_left"/>
    <origin xyz="0.250 0.095 -0.0144" rpy="0 1.5707963 0.7853982"/>
    <axis xyz="0 0 1"/>
    <dynamics damping="0.005" friction="0.0"/>
  </joint>

  <link name="t2_front_right">
    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
    <inertial><mass value="0.344"/>
      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</inertial>
  </link>
  <joint name="t2_front_right_joint" type="continuous">
    <parent link="base_link"/><child link="t2_front_right"/>
    <origin xyz="0.250 -0.095 -0.0144" rpy="0 1.5707963 -0.7853982"/>
    <axis xyz="0 0 1"/>
    <dynamics damping="0.005" friction="0.0"/>
  </joint>

  <link name="t3_rear_left">
    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
    <inertial><mass value="0.344"/>
      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</inertial>
  </link>
  <joint name="t3_rear_left_joint" type="continuous">
    <parent link="base_link"/><child link="t3_rear_left"/>

    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
    <origin xyz="-0.250 0.095 -0.0144" rpy="0 1.5707963 2.3561945"/>
    <axis xyz="0 0 1"/>
    <dynamics damping="0.005" friction="0.0"/>
  </joint>

  <link name="t4_rear_right">
    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
    <inertial><mass value="0.344"/>
      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</inertial>
  </link>
  <joint name="t4_rear_right_joint" type="continuous">
    <parent link="base_link"/><child link="t4_rear_right"/>
    <origin xyz="-0.250 -0.095 -0.0144" rpy="0 1.5707963 -2.3561945"/>
    <axis xyz="0 0 1"/>
    <dynamics damping="0.005" friction="0.0"/>
  </joint>

  <link name="t5_vert_front">
    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
    <inertial><mass value="0.344"/>
      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</inertial>
  </link>
  <joint name="t5_vert_front_joint" type="continuous">
    <parent link="base_link"/><child link="t5_vert_front"/>
    <origin xyz="0.305 0 -0.0063" rpy="0 0 0"/>
    <axis xyz="0 0 1"/>
    <dynamics damping="0.005" friction="0.0"/>
  </joint>

  <link name="t6_vert_rear">
    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
    <inertial><mass value="0.344"/>
      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</inertial>
  </link>
  <joint name="t6_vert_rear_joint" type="continuous">
    <parent link="base_link"/><child link="t6_vert_rear"/>
    <origin xyz="-0.305 0 -0.0063" rpy="0 0 0"/>
    <axis xyz="0 0 1"/>
    <dynamics damping="0.005" friction="0.0"/>
  </joint>

  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
  <link name="imu_link"/>
  <joint name="imu_joint" type="fixed">
    <parent link="base_link"/><child link="imu_link"/>
    <origin xyz="0 0 0" rpy="0 0 0"/>
  </joint>
  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

  <link name="camera_link"/>
  <joint name="camera_joint" type="fixed">
    <parent link="base_link"/><child link="camera_link"/>
    <origin xyz="0.1274 0 0" rpy="0 0 0"/>
  </joint>
  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

  <link name="dvl_link"/>
  <joint name="dvl_joint" type="fixed">
    <parent link="base_link"/><child link="dvl_link"/>
    <origin xyz="-0.0850 0 -0.1083" rpy="0 0 0"/>
  </joint>

</robot>

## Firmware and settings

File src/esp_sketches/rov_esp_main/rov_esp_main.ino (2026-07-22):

#include <micro_ros_arduino.h>
#include <ESP32Servo.h>
#include <HardwareSerial.h>
#include <stdio.h>
#include <rcl/rcl.h>
#include <rcl/error_handling.h>
#include <rclc/rclc.h>
#include <rclc/executor.h>
#include <std_msgs/msg/int32.h>
#include <geometry_msgs/msg/twist.h>
#include <geometry_msgs/msg/vector3.h>
#include <std_msgs/msg/float64.h>
#include <Wire.h>
#include <Adafruit_Sensor.h>
#include <Adafruit_BNO055.h>
#include <Adafruit_BME280.h>
// #include <Adafruit_MPU6050.h>
// #include <SparkFun_Qwiic_OLED.h> //http://librarymanager/All#SparkFun_Qwiic_OLED
#include "MS5837.h"

#define SEALEVELPRESSURE_HPA (1013.25)
#define RCCHECK(fn) ((fn) == RCL_RET_OK)

#define INDICATOR_LED_PIN 0 // green LED: micro-ROS link status
#define RED_LED_PIN 5        // red LED: fault/attention by priority (leak > sensor fault > armed)
#define LEAK_PIN 15
#define DEBUG_TX_PIN 17
#define DEBUG_RX_PIN 16
#define ESC_MIN 1100
#define ESC_MAX 1900
#define LIGHT_MIN 1100
#define LIGHT_MAX 1900
#define CAM_SERVO_MIN 0
#define CAM_SERVO_MAX 180

//========================== Pinout =========================================================
Servo esc1, esc2, esc3, esc4, esc5, esc6;
Servo light_single, light_couple, light_single_pair;
Servo cam_servo;
MS5837 bar100;
Adafruit_BNO055 bno = Adafruit_BNO055(55);
Adafruit_BME280 bme;
HardwareSerial MainSerial(0);  // Declaring a Serial object on UART0
HardwareSerial DebugSerial(1); // Use UART1 for debugging

int esc_pins[] = {27, 26, 25, 33, 32, 14};
int light_pins[] = {18, 19}; // light_single, light_couple
int cam_servo_pin = 13;
int light_single_pair_pin = 4; // extra light, mirrors light_couple = the single light (B button)

//========================== Publishers definitions =========================================
rcl_publisher_t leak_pub;
std_msgs__msg__Float64 leak_msg;
rcl_publisher_t bno055_pub;
geometry_msgs__msg__Twist bno055_msg;
rcl_publisher_t bar100_pub;
geometry_msgs__msg__Vector3 bar100_msg;
rcl_publisher_t bme280_pub;
geometry_msgs__msg__Vector3 bme280_msg;
//========================== Subscribers definitions ========================================
rcl_subscription_t motors_sub;
rcl_subscription_t lights_servo_sub;
geometry_msgs__msg__Twist motors_msg;
geometry_msgs__msg__Vector3 lights_servo_msg;
//========================== ROS variables ==================================================
rclc_executor_t executor;
rclc_support_t support;
rcl_allocator_t allocator;
rcl_node_t node;
rcl_timer_t sensor_timer;
enum states {
    WAITING_AGENT,
    AGENT_AVAILABLE,
    AGENT_CONNECTED,
    AGENT_DISCONNECTED
} state;

unsigned long delayTime;
bool bar100_initialized = false;
bool bme280_initialized = false;
bool bno055_initialized = false;
volatile bool g_armed = false;   // any thruster commanded off-neutral (props may spin)

// Status-LED blink patterns; applyLed() renders them with millis() so nothing blocks.
enum LedPattern { LED_OFF, LED_SOLID, LED_SLOW, LED_FAST };


//========================== Subscribers Callbacks ==========================================
void subscription_callback_motors(const void *msgin) {
    const geometry_msgs__msg__Twist *msg = (const geometry_msgs__msg__Twist *)msgin;
    int motor1_val = static_cast<int>(msg->linear.x);
    int motor2_val = static_cast<int>(msg->linear.y);
    int motor3_val = static_cast<int>(msg->linear.z);
    int motor4_val = static_cast<int>(msg->angular.x);
    int motor5_val = static_cast<int>(msg->angular.y);
    int motor6_val = static_cast<int>(msg->angular.z);

    // "Armed" for the red status LED: any valid motor command more than ~20 us
    // off neutral means a thruster is being driven (props may spin).
    int mvals[6] = {motor1_val, motor2_val, motor3_val, motor4_val, motor5_val, motor6_val};
    bool armed = false;
    for (int i = 0; i < 6; i++) {
        if (mvals[i] >= ESC_MIN && mvals[i] <= ESC_MAX && abs(mvals[i] - 1500) > 20) armed = true;
    }
    g_armed = armed;

    if (motor1_val >= ESC_MIN && motor1_val <= ESC_MAX) {
        esc1.writeMicroseconds(motor1_val);
    }
    if (motor2_val >= ESC_MIN && motor2_val <= ESC_MAX) {
        esc2.writeMicroseconds(motor2_val);
    }
    if (motor3_val >= ESC_MIN && motor3_val <= ESC_MAX) {
        esc3.writeMicroseconds(motor3_val);
    }
    if (motor4_val >= ESC_MIN && motor4_val <= ESC_MAX) {
        esc4.writeMicroseconds(motor4_val);
    }
    if (motor5_val >= ESC_MIN && motor5_val <= ESC_MAX) {
        esc5.writeMicroseconds(motor5_val);
    }
    if (motor6_val >= ESC_MIN && motor6_val <= ESC_MAX) {
        esc6.writeMicroseconds(motor6_val);
    }
}

void subscription_callback_lights_servo(const void *msgin) {
    const geometry_msgs__msg__Vector3 *msg = (const geometry_msgs__msg__Vector3 *)msgin;
    int light_single_val = static_cast<int>(msg->x);
    int light_couple_val = static_cast<int>(msg->y);
    int cam_servo_val = static_cast<int>(msg->z);

    if (light_single_val >= LIGHT_MIN && light_single_val <= LIGHT_MAX) {
        light_single.writeMicroseconds(light_single_val);
    }
    if (light_couple_val >= LIGHT_MIN && light_couple_val <= LIGHT_MAX) {
        light_couple.writeMicroseconds(light_couple_val);
        // GPIO 4 light pairs with the PHYSICAL single light (B button). Note the
        // code names are reversed vs the wiring: light_single (msg->x, A button)
        // is the 2-light pair; light_couple (msg->y, B button) is the single light.
        light_single_pair.writeMicroseconds(light_couple_val);
    }
    if (cam_servo_val >= CAM_SERVO_MIN && cam_servo_val <= CAM_SERVO_MAX) {
        cam_servo.write(cam_servo_val);
    }
}

void sensors_timer_callback(rcl_timer_t *timer, int64_t last_call_time) {
    RCLC_UNUSED(last_call_time);
    sensors_event_t orientationData;
    bno.getEvent(&orientationData, Adafruit_BNO055::VECTOR_EULER);

    bno055_msg.linear.x = static_cast<double>(orientationData.orientation.x);
    bno055_msg.linear.y = static_cast<double>(orientationData.orientation.y);
    bno055_msg.linear.z = static_cast<double>(orientationData.orientation.z);
    bno055_msg.angular.x = 0.0;
    bno055_msg.angular.y = 0.0;
    bno055_msg.angular.z = 0.0;
    if (!RCCHECK(rcl_publish(&bno055_pub, &bno055_msg, NULL))) {
        DebugSerial.println("Failed publishing bno055 message");
    }

    leak_msg.data = (double)digitalRead(LEAK_PIN);
    if (!RCCHECK(rcl_publish(&leak_pub, &leak_msg, NULL))) {
        DebugSerial.println("Failed publishing leak message");
    }
    if (leak_msg.data) {
        DebugSerial.println("!!! LEAK DETECTED !!!");
    }

    if (bar100_initialized) {
        bar100.read();
        bar100_msg.x = static_cast<double>(bar100.depth());
        bar100_msg.y = static_cast<double>(bar100.pressure());
        bar100_msg.z = static_cast<double>(bar100.temperature());
        if (!RCCHECK(rcl_publish(&bar100_pub, &bar100_msg, NULL))) {
            DebugSerial.println("Failed publishing bar100 message");
        }
    }

    if (bme280_initialized) {
        bme280_msg.x = static_cast<double>(bme.readTemperature());
        bme280_msg.y = static_cast<double>(bme.readPressure() / 100.0);
        bme280_msg.z = static_cast<double>(bme.readHumidity());
        if (!RCCHECK(rcl_publish(&bme280_pub, &bme280_msg, NULL))) {
            DebugSerial.println("Failed publishing bme280 message");
        }
    }
}

void cleanup_ros_entities() {
    rmw_context_t * rmw_context = rcl_context_get_rmw_context(&support.context);
    (void) rmw_uros_set_context_entity_destroy_session_timeout(rmw_context, 0);
    rcl_timer_fini(&sensor_timer);
    rcl_publisher_fini(&bno055_pub, &node);
    rcl_publisher_fini(&leak_pub, &node);
    rcl_publisher_fini(&bar100_pub, &node);
    rcl_publisher_fini(&bme280_pub, &node);
    rcl_subscription_fini(&motors_sub, &node);
    rcl_subscription_fini(&lights_servo_sub, &node);
    rclc_executor_fini(&executor);
    rclc_support_fini(&support);
    rcl_node_fini(&node);
}

bool setup_node_and_entities() {
    DebugSerial.println("____________________________________________\nStarting Setup:");
    set_microros_transports();
    allocator = rcl_get_default_allocator();
    RCCHECK(rclc_support_init(&support, 0, NULL, &allocator));
    RCCHECK(rclc_node_init_default(&node, "esp32_node", "", &support));
    RCCHECK(rclc_publisher_init_default(&bno055_pub, &node, ROSIDL_GET_MSG_TYPE_SUPPORT(geometry_msgs, msg, Twist), "/esp32/bno055_data"));
    RCCHECK(rclc_publisher_init_default(&bar100_pub, &node, ROSIDL_GET_MSG_TYPE_SUPPORT(geometry_msgs, msg, Vector3), "/esp32/bar100_data"));
    RCCHECK(rclc_publisher_init_default(&leak_pub, &node, ROSIDL_GET_MSG_TYPE_SUPPORT(std_msgs, msg, Float64), "/esp32/leak"));
    RCCHECK(rclc_publisher_init_default(&bme280_pub, &node, ROSIDL_GET_MSG_TYPE_SUPPORT(geometry_msgs, msg, Vector3), "/esp32/bme280_data"));
    RCCHECK(rclc_timer_init_default(&sensor_timer, &support, RCL_MS_TO_NS(50), sensors_timer_callback));
    RCCHECK(rclc_executor_init(&executor, &support.context, 6, &allocator));
    RCCHECK(rclc_executor_add_timer(&executor, &sensor_timer));
    RCCHECK(rclc_subscription_init_default(&motors_sub, &node, ROSIDL_GET_MSG_TYPE_SUPPORT(geometry_msgs, msg, Twist), "/motor_data"));
    RCCHECK(rclc_executor_add_subscription(&executor, &motors_sub, &motors_msg, subscription_callback_motors, ON_NEW_DATA));
    RCCHECK(rclc_subscription_init_default(&lights_servo_sub, &node, ROSIDL_GET_MSG_TYPE_SUPPORT(geometry_msgs, msg, Vector3), "/lights_servo_data"));
    RCCHECK(rclc_executor_add_subscription(&executor, &lights_servo_sub, &lights_servo_msg, subscription_callback_lights_servo, ON_NEW_DATA));
    DebugSerial.println("____________________________________________");
    return true;
}

void setup() {
    set_microros_transports();
    pinMode(INDICATOR_LED_PIN, OUTPUT);
    pinMode(RED_LED_PIN, OUTPUT);
    pinMode(LEAK_PIN, INPUT);
    digitalWrite(INDICATOR_LED_PIN, LOW);  // updateStatusLeds() drives both from loop()
    digitalWrite(RED_LED_PIN, LOW);
    state = WAITING_AGENT;
    DebugSerial.begin(115200, SERIAL_8N1, DEBUG_RX_PIN, DEBUG_TX_PIN);
    MainSerial.begin(115200);
    DebugSerial.println("Starting setup...");
    // Give the ESP32Servo library all 4 hardware timers BEFORE attaching servos.
    // Without this, driving many servos (6 ESC + 2 lights + cam) leaves the later
    // attaches (e.g. cam_servo) without a timer, so they silently fail — a single
    // servo works, but the full 9-servo setup does not.
    ESP32PWM::allocateTimer(0);
    ESP32PWM::allocateTimer(1);
    ESP32PWM::allocateTimer(2);
    ESP32PWM::allocateTimer(3);
    esc1.attach(esc_pins[0]);
    esc2.attach(esc_pins[1]);
    esc3.attach(esc_pins[2]);
    esc4.attach(esc_pins[3]);
    esc5.attach(esc_pins[4]);
    esc6.attach(esc_pins[5]);
    cam_servo.setPeriodHertz(50);
    cam_servo.attach(cam_servo_pin, 500, 2400);
    light_single.attach(light_pins[0]);
    light_couple.attach(light_pins[1]);
    light_single_pair.attach(light_single_pair_pin);
    esc1.writeMicroseconds(1500);
    esc2.writeMicroseconds(1500);
    esc3.writeMicroseconds(1500);
    esc4.writeMicroseconds(1500);
    esc5.writeMicroseconds(1500);
    esc6.writeMicroseconds(1500);
    light_single.writeMicroseconds(1100);
    light_couple.writeMicroseconds(1100);
    light_single_pair.writeMicroseconds(1100);
    cam_servo.write(90);

    Wire.begin();
    if (bar100.init()) {
        bar100_initialized = true;
        bar100.setFluidDensity(997);
        DebugSerial.println("Bar100 is connected.");
    } else {
        bar100_initialized = false;
        DebugSerial.println("Bar100 failed to initialize.");
    }
    if (!bno.begin()) {
        bno055_initialized = false;
        DebugSerial.println("Failed to find BNO055 chip.");
    } else {
        bno055_initialized = true;
        bno.setExtCrystalUse(true);
    }
    if (!bme.begin(0x77)) {
        bme280_initialized = false;
        DebugSerial.println("BME280 failed to initialize.");
    } else {
        bme280_initialized = true;
        DebugSerial.println("BME280 connected.");
    }
    DebugSerial.println("Finished Setup.");
    DebugSerial.println("Waiting for Agent...");
}

// Render a pattern on an LED using millis(), so it never blocks the loop.
void applyLed(int pin, LedPattern pat) {
    bool on = false;
    switch (pat) {
        case LED_SOLID: on = true; break;
        case LED_SLOW:  on = (millis() % 1000) < 500; break;   // ~1 Hz
        case LED_FAST:  on = (millis() % 250)  < 125; break;   // ~4 Hz
        case LED_OFF:
        default:        on = false; break;
    }
    digitalWrite(pin, on ? HIGH : LOW);
}

// Drive both status LEDs from the current state. Called every loop().
//   GREEN (GPIO0) = micro-ROS link: solid=connected, slow-blink=searching, off=down.
//   RED   (GPIO5) = fault/attention, highest priority wins:
//                   fast=LEAK, solid=sensor fault, slow=armed, off=all clear.
void updateStatusLeds() {
    LedPattern green;
    if (state == AGENT_CONNECTED)         green = LED_SOLID;
    else if (state == AGENT_DISCONNECTED) green = LED_OFF;
    else                                  green = LED_SLOW;   // WAITING / AVAILABLE = searching
    applyLed(INDICATOR_LED_PIN, green);

    // Leak is read straight off the pin (not via ROS), so the alarm still works
    // even when the ESP32 is disconnected from the agent.
    bool leak = digitalRead(LEAK_PIN);
    bool sensor_fault = !bno055_initialized || !bar100_initialized || !bme280_initialized;

    LedPattern red;
    if (leak)              red = LED_FAST;
    else if (sensor_fault) red = LED_SOLID;
    else if (g_armed)      red = LED_SLOW;
    else                   red = LED_OFF;
    applyLed(RED_LED_PIN, red);
}

void loop() {
    updateStatusLeds();
    switch (state) {
        case WAITING_AGENT:
            if (RMW_RET_OK == rmw_uros_ping_agent(1000, 3)) {
                state = AGENT_AVAILABLE;
                DebugSerial.println("Found Agent!");
            }
            break;
        case AGENT_AVAILABLE:
            setup_node_and_entities();
            state = AGENT_CONNECTED;
            DebugSerial.println("Connected to Agent!");
            break;
        case AGENT_CONNECTED:
            if (RMW_RET_OK == rmw_uros_ping_agent(100, 1)) {
                rclc_executor_spin_some(&executor, RCL_MS_TO_NS(100));
            } else {
                DebugSerial.println("Disconnected from Agent");
                state = AGENT_DISCONNECTED;
            }
            break;
        case AGENT_DISCONNECTED:
            cleanup_ros_entities();
            state = WAITING_AGENT;
            break;
        default:
            break;
    }
}

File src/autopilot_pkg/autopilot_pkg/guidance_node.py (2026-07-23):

import rclpy
from rclpy.node import Node
from sensor_msgs.msg import Joy, NavSatFix
from geometry_msgs.msg import Twist, Vector3
from nav_msgs.msg import Odometry
from std_msgs.msg import String, Float64
import math
import time

# If no joystick/acoustic command arrives within this window, zero the thruster
# inputs (failsafe) so a dropped control link can't leave motors driving.
JOY_FAILSAFE_TIMEOUT = 1.5  # seconds

# ── Auto-GOTO (surface GPS navigation) ───────────────────────────────────────
GOTO_ARRIVAL_M     = 4.0     # m — within this of target = arrived (keep > GPS jitter)
GOTO_SLOWDOWN_M    = 12.0    # m — start ramping forward thrust down inside this range
GOTO_MAX_FWD       = 0.6     # 0..1 forward-thrust cap (raise toward 1.0 for "full speed")
GOTO_YAW_FULL      = 45.0    # deg heading error that commands full yaw
GOTO_ALIGN_DEG     = 45.0    # deg — only drive forward when heading error is under this
GOTO_MAX_DIST      = 1000.0  # m — ignore/cancel targets farther than this (sanity)
GOTO_ABORT_AXIS    = 0.2     # joystick deflection that cancels auto and returns to manual
GOTO_COMMS_TIMEOUT = 5.0     # s without /joy while navigating -> stop (lost operator link)
GOTO_HOLD_DEADZONE_M = 1.5   # within this of target: hold (no horizontal thrust), just depth
GOTO_LOITER_FWD      = 0.25  # gentle forward-thrust cap while loitering (in the hold zone)
GOTO_DEPTH_KP        = 0.35  # vertical thrust (0..1) per metre of depth error
GOTO_DEPTH_DEADBAND  = 0.3   # m — within this of the target depth, no vertical thrust
GOTO_VERT_MAX        = 0.5   # cap on the depth-hold vertical thrust

# ── Leak → auto-surface failsafe ─────────────────────────────────────────────
LEAK_TRIGGER_N = 2      # consecutive leak readings before the failsafe latches (debounce)
LEAK_ASCEND    = 0.8    # vertical thrust (0..1) for the emergency ascent
LEAK_SURFACE_M = 0.4    # m — with a fresh depth at/above this, stop ascending (hold at surface)
LEAK_CLEAR_SEC = 5.0    # s the sensor must read dry before auto-clearing back to manual

class GuidanceNode(Node):
    def __init__(self):
        super().__init__('guidance_node')
        self.get_logger().info(f"Guidance Node has been started!")

        # Publishers
        self.motors_publisher = self.create_publisher(Twist, '/motor_data', 10)
        self.lights_publisher = self.create_publisher(Vector3, '/lights_servo_data', 10)
        self.odometry_publisher = self.create_publisher(Odometry, '/odometry', 10)

        # Subscribers
        self.orientation_subscription = self.create_subscription(Twist, '/esp32/bno055_data', self.orientation_callback, 10)
        self.dvl_subscription = self.create_subscription(Twist, '/dvl/velocity_data', self.dvl_callback, 10)
        self.joy_subscription = self.create_subscription(Joy, '/joy', self.joy_callback, 10)
        # Acoustic link commands (from acoustic_bridge_node) drive guidance the
        # same way as a physical joystick — used for untethered QGC control.
        self.joy_acoustic_subscription = self.create_subscription(Joy, '/joy_acoustic', self.joy_callback, 10)
        self.bar100_subscription = self.create_subscription(Vector3, '/esp32/bar100_data', self.bar100_callback, 10)
        self.qgc_mode_subscription = self.create_subscription(String, '/qgc_mode', self.qgc_mode_callback, 10)
        # Auto-GOTO: current fix + target destination (target comes from mavlink_bridge)
        self.gps_subscription = self.create_subscription(NavSatFix, '/gps/fix', self.gps_callback, 10)
        self.goto_subscription = self.create_subscription(NavSatFix, '/guidance/goto_target', self.goto_callback, 10)
        # Leak sensor (0.0 dry / 1.0 leak) — drives the auto-surface failsafe
        self.leak_subscription = self.create_subscription(Float64, '/esp32/leak', self.leak_callback, 10)

        # Timers
        self.motor_light_pub_timer = self.create_timer(0.05, self.motor_light_publisher)  # 20 Hz

        # Variables
        self.start_time = self.get_clock().now()
        self.orientation = {"x": 0.0, "y": 0.0, "z": 0.0}
        self.dvl_velocities = {"vx": 0.0, "vy": 0.0, "vz": 0.0}
        self.motor_velocity = {"motor1": 1500, "motor2": 1500, "motor3": 1500, "motor4": 1500, "motor5": 1500, "cam_servo": 90, "motor6": 1500}
        self.light_intensity = {"light_single": 1100, "light_couple": 1100}
        self.joystick_axes = [0.0] * 6
        self.joystick_buttons = [0] * 16
        self.joy_cam_up = 1.0
        self.joy_cam_down = 1.0
        self.joystick_mode = True
        self.previous_button_states = [False] * 16
        self._last_joy_time = 0.0   # for control-link failsafe

        # Auto-GOTO state
        self.gps = {"lat": 0.0, "lon": 0.0, "fix": False}
        self.goto_target = None        # {"lat","lon"} while navigating
        self.auto_goto_active = False
        self.depth = 0.0               # current depth (m) from BAR100
        self.goto_depth = 0.0          # depth to hold during GOTO (captured at engage)
        self._loitering = False

        # Leak → auto-surface failsafe (latched; overrides every other control)
        self.leak_value = 0.0
        self.leak_failsafe = False
        self._leak_count = 0
        self._leak_dry_since = None
        self._last_bar_time = 0.0      # freshness of the depth reading

        # Target orientation in autonomous mode
        self.target_orientation = {"x": 0.0, "y": 0.0, "z": 0.0}

        # PID constants
        self.kp_yaw = 15.0
        self.kd_yaw = 2.0
        self.kp_pitch = 15.0
        self.kd_pitch = 2.0
        self.kp_roll = 15.0
        self.kd_roll = 2.0
        self.state_estimate = [0.0, 0.0, 0.0]

        # Safety envelope — attitude limits
        self.ENVELOPE_ENABLED = False  # disabled until IMU offset is calibrated
        self.ENVELOPE_WARN  = 30.0   # deg — begin scaling inputs
        self.ENVELOPE_HARD  = 50.0   # deg — zero inputs, max correction
        self.ENVELOPE_GAIN  = 6.0    # PWM correction per degree beyond warn
        self._envelope_active = False
        # IMU mount offsets — auto-calibrated from first readings on startup
        self.PITCH_OFFSET   = 0.0
        self.ROLL_OFFSET    = 0.0
        self._offset_samples_pitch = []
        self._offset_samples_roll  = []
        self._OFFSET_N = 20   # number of readings to average

    def orientation_callback(self, msg):
        self.orientation["x"] = msg.linear.x
        self.orientation["y"] = msg.linear.y
        self.orientation["z"] = msg.linear.z
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
